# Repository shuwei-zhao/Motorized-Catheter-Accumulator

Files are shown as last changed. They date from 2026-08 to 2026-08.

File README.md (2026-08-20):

# Motorized Catheter Accumulation System

A research prototype for managing the free length of a long, flexible catheter with a translating large-pulley accumulator driven by a lead-screw stepper stage.

> [!IMPORTANT]
> This repository documents only the catheter accumulation and recovery mechanism. The magnetic steering robot, catheter propulsion module, and demonstration specimen shown in the system overview are integration context and are not implemented in this repository.

## 1. Overview

Long magnetic catheters require controlled length management during experiments. Unmanaged excess length can bend unpredictably, become entangled, reduce experimental repeatability, and make manual handling difficult.

This prototype addresses that problem with a motorized translating-pulley accumulator. A large guiding pulley is mounted on a linear carriage and moves along an MGN12 rail. The catheter is routed around the pulley, so translating the carriage changes the available routing length without winding the catheter onto a rotating spool. A T8 lead screw and stepper motor provide linear actuation, while an Arduino UNO and a Python desktop application provide motion control.

The intended use is laboratory research involving long flexible catheters, including experiments in which the accumulator operates alongside a separate propulsion mechanism and robotic magnetic steering system.

## 2. System Architecture

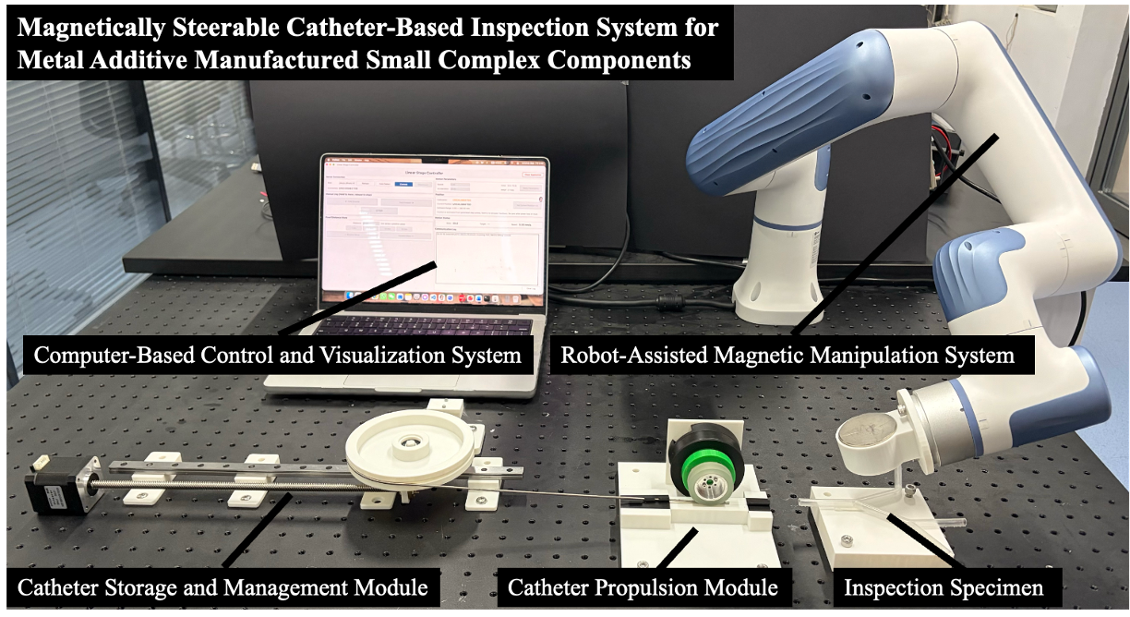
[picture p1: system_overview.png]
Integrated experimental system showing the catheter accumulator in context


The overview image shows the complete experimental setup. The accumulator is the linear module at the lower left; the other labeled modules are outside this repository's scope.

The accumulator consists of three functional layers:

- **Catheter accumulation mechanism:** a large pulley with a catheter groove redirects the catheter and changes the managed path length as it translates.
- **Linear motion stage:** an MGN12 rail, MGN12H carriage, carriage adapter, T8 lead screw, and motor convert rotary motion into controlled horizontal translation.
- **Motor control system:** a Python host application communicates with an Arduino UNO over USB serial. The Arduino generates `STEP` and `DIR` signals for a TB6600 stepper driver.

## 3. Mechanical Design Principle

The mechanism is a translating pulley accumulator, not a reel or driven spool. The pulley rotates passively to guide the catheter, while the entire pulley assembly translates along the linear axis.

```text
Stepper motor rotation
        |
        v
Lead screw rotation
        |
        v
Lead-screw nut translation
        |
        v
Linear carriage movement
        |
        v
Large pulley translation
        |
        v
Change in catheter routing length
        |
        v
Catheter accumulation or release
```

When the moving pulley is supported by two approximately parallel catheter segments, translating it changes both segments by nearly the same amount. The first-order geometric relationship is therefore:

**ΔL ≈ 2Δx**

where:

- `ΔL` is the change in managed catheter length.
- `Δx` is the pulley translation distance.

This approximation assumes that the fixed routing points remain stationary and that changes in wrap geometry, catheter stretch, slip, and elastic deformation are small. The sign of `ΔL` depends on the selected positive carriage direction and routing convention.

## 4. Hardware Components

### Mechanical components

| Component | Specification or role |
| --- | --- |
| Linear rail | MGN12, 400 mm guide rail |
| Linear carriage | MGN12H carriage block |
| Carriage adapter | 3D-printed interface between the carriage, pulley assembly, and lead-screw nut |
| Guide pulley | Large pulley with a U-shaped catheter groove |
| Pulley bearings | 608 bearings supporting passive pulley rotation |
| Pulley shaft | Vertical shaft through the bearing-supported pulley |
| Pulley support | 3D-printed support structure for the shaft and bearings |
| Lead screw | T8 lead screw with an 8 mm lead |
| Nominal actuator travel | 300 mm mechanical travel; the supplied control software limits commanded position to 0-280 mm |

### Electrical components

| Component | Role |
| --- | --- |
| Arduino UNO R3 | Serial command handling and real-time step-pulse generation |
| TB6600 stepper driver | Motor phase-current control from `STEP` and `DIR` inputs |
| Lead-screw stepper motor | Drives the T8 lead screw |
| 24 V, 1.5 A laboratory supply | Powers the motor driver and stepper stage |
| Computer | Runs the Python control interface and supplies the USB serial connection |

The firmware is configured for a 200-full-step motor, 8 microsteps, and an 8 mm lead screw, which gives 200 command pulses per millimetre. Confirm the motor, driver switch settings, lead-screw lead, and available supply current before operation.

## 5. Electronics Connection

### Control chain

```text
Computer
   |
Python interface
   |
USB serial at 115200 baud
   |
Arduino UNO R3
   |
STEP / DIR
   |
TB6600 driver
   |
Stepper motor
   |
T8 lead screw and translating pulley carriage
```

### Arduino-to-driver signals

The supplied firmware uses the following common-anode input wiring:

| Arduino UNO | TB6600 input |
| --- | --- |
| `5V` | `PUL+` and `DIR+` |
| Digital pin `D2` | `PUL-` |
| Digital pin `D3` | `DIR-` |
| Not connected | `ENA+` and `ENA-` |

The 24 V supply connects to the TB6600 power input, and the stepper motor connects to the driver's motor outputs according to the driver and motor documentation. Disconnect power before changing wiring. Do not power the motor from the Arduino.

If the application's **Forward** command produces the wrong physical direction, change `FORWARD_DIR_LEVEL` in the Arduino firmware from `HIGH` to `LOW`, then compile and upload it again.

## 6. Software Usage

### Arduino firmware

The Arduino sketch is located at:

```text
Software/Arduino/Catheter_Accumulator_Controller/Catheter_Accumulator_Controller.ino
```

To upload it:

1. Disconnect motor power and verify the signal wiring.
2. Open the sketch in the Arduino IDE.
3. Select **Arduino UNO** and the correct USB serial port.
4. Compile and upload the sketch.
5. Reconnect motor power only after checking the driver current and microstep settings.

No third-party Arduino library is required. The sketch uses Arduino core headers and standard C/C++ headers.

### Python controller

The host application is located at:

```text
Software/Python/Catheter_Accumulator_Controller.py
```

Python 3 with Tkinter is required. Create an isolated environment and install the serial dependency:

```bash
cd Software/Python
python3 -m venv .venv
source .venv/bin/activate
python -m pip install -r requirements.txt
python Catheter_Accumulator_Controller.py
```

On Windows, activate the environment with `.venv\Scripts\activate` before running the final two commands. If Tkinter is not included with the Python installation, install the platform's Tk package separately.

### Initial operation

1. Power the control electronics and start the Python application.
2. Refresh the serial-port list, select the Arduino, and connect.
3. At low speed, hold the jog control to move the carriage to the chosen mechanical zero position.
4. Select **Set Current Position = 0**.
5. Enter the desired speed, acceleration, and move distance, then command forward or reverse motion.
6. Use **STOP** immediately if the mechanism approaches an obstruction or travel boundary.

The application supports manual jogging, fixed-distance moves, speed and acceleration settings, status reporting, and stop commands. Communication uses newline-terminated ASCII messages at 115200 baud.

> [!WARNING]
> The prototype has no encoder, home sensor, physical limit switch, tension sensor, or emergency-stop circuit. Position is estimated from generated step pulses. The Arduino returns to `UNCALIBRATED` after every reset or power cycle, so the carriage must be re-zeroed manually. The 0-280 mm software limits do not replace physical travel protection.

The firmware communication watchdog stops motion if valid host contact is absent for more than one second. Begin commissioning with low speed and short moves, keep a power disconnect accessible, and prevent the catheter, wiring, and operator from entering pinch points.

## 7. CAD Files

Native CAD sources are stored in [`Hardware/CAD`](Hardware/CAD). They include the large guide pulley, MGN12H carriage adapter, rail base platform, fixed catheter clamp, and compliant-pad mold components.

The current archive contains Autodesk Fusion `.f3d` files and one SOLIDWORKS `.SLDPRT` file. It does not yet include validated STL exports, STEP exchange files, manufacturing drawings, tolerances, or print settings. See the [CAD inventory](Hardware/CAD/README.md) for file-level descriptions.

## 8. Repository Structure

```text
Motorized-Catheter-Accumulator/
├── README.md
├── system_overview.png
├── Software/
│   ├── Arduino/
│   │   └── Catheter_Accumulator_Controller/
│   │       └── Catheter_Accumulator_Controller.ino
│   └── Python/
│       ├── Catheter_Accumulator_Controller.py
│       └── requirements.txt
├── Hardware/
│   └── CAD/
│       ├── README.md
│       ├── Ecoflex_Pad_Mold_Bottom.f3d
│       ├── Ecoflex_Pad_Mold_Top.f3d
│       ├── Fixed_Catheter_Clamp.f3d
│       ├── Guide_Pulley_120mm.f3d
│       ├── Linear_Rail_Base_Platform.SLDPRT
│       └── MGN12H_Carriage_Adapter.f3d
└── .gitignore
```

## 9. Future Development

Possible research extensions include:

- Closed-loop carriage position control with an encoder or linear scale.
- A repeatable homing procedure using limit or home sensors.
- Direct measurement of catheter tension and automatic tension regulation.
- Physical end-of-travel protection and a dedicated emergency-stop circuit.
- Calibration of the relationship between carriage displacement and managed catheter length.
- Coordinated control with a separate catheter propulsion module.
- Integration with a robotic magnetic steering system for complete experimental workflows.

## Research Status

This repository describes an academic research prototype. It is not a medical device, a clinical system, or a commercial product. Verify all mechanical, electrical, and software behavior independently before experimental use.

No open-source license has been granted. Because this is a private research repository, redistribution and reuse require permission from the project owner.

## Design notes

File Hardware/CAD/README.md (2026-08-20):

# CAD Files

This directory contains native CAD source files for the motorized catheter accumulator research prototype. The models should be reviewed against the as-built hardware before manufacturing replacements.

| File | Format | Intended role |
| --- | --- | --- |
| `MGN12H_Carriage_Adapter.f3d` | Autodesk Fusion archive | Connects the pulley assembly and lead-screw nut to the MGN12H carriage |
| `Guide_Pulley_120mm.f3d` | Autodesk Fusion archive | Large catheter-routing pulley |
| `Linear_Rail_Base_Platform.SLDPRT` | SOLIDWORKS part | Base platform beneath the linear rail |
| `Fixed_Catheter_Clamp.f3d` | Autodesk Fusion archive | Fixed catheter clamp component |
| `Ecoflex_Pad_Mold_Top.f3d` | Autodesk Fusion archive | Upper part of the compliant pad mold or fixture |
| `Ecoflex_Pad_Mold_Bottom.f3d` | Autodesk Fusion archive | Lower part of the compliant pad mold |

The repository currently contains the available native CAD sources only. Mesh exports, neutral STEP files, manufacturing drawings, and verified print settings are not yet included.

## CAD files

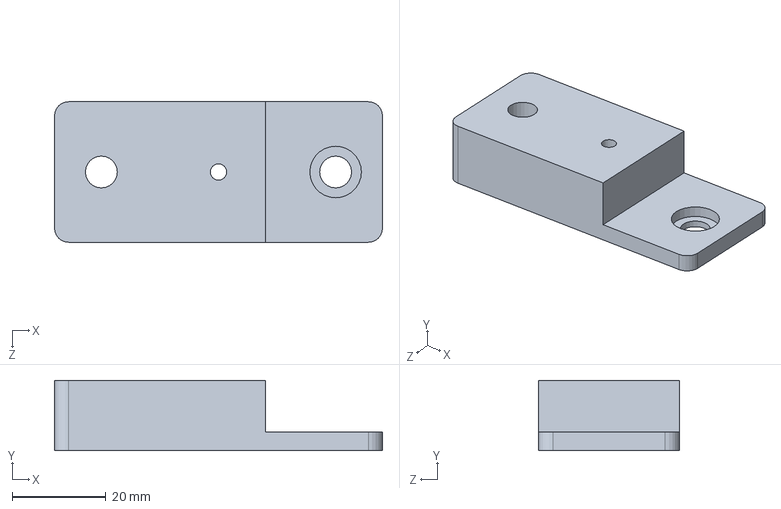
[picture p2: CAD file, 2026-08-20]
Hardware/CAD/Linear_Rail_Base_Platform.SLDPRT
70.0 x 15.0 x 30.0 mm

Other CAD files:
Hardware/CAD/Ecoflex_Pad_Mold_Bottom.f3d
Hardware/CAD/Ecoflex_Pad_Mold_Top.f3d
Hardware/CAD/Fixed_Catheter_Clamp.f3d
Hardware/CAD/Guide_Pulley_120mm.f3d
Hardware/CAD/MGN12H_Carriage_Adapter.f3d

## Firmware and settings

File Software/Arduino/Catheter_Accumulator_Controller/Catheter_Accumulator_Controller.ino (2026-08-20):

// ============================================================================
// Motorized catheter accumulator firmware for Arduino UNO R3, TB6600, and T8 stage
//
// Verified common-anode wiring:
//   Arduino 5V -> PUL+ / DIR+
//   Arduino D2 -> PUL-
//   Arduino D3 -> DIR-
//   ENA not connected
//
// The optocoupler conducts while PUL- is LOW, so the idle PUL level must be HIGH.
// Motor: 200 full steps/rev * 8 microsteps / 8 mm lead = 200 pulses/mm.
//
// Direction check:
// If Forward in the GUI moves the stage in the wrong physical direction, change
// FORWARD_DIR_LEVEL below from HIGH to LOW and upload the firmware again.
//
// This system has no encoder, home sensor, or physical limit switch. Position is
// estimated only from step pulses that were actually generated. Every power cycle
// or reset starts in UNCALIBRATED; the firmware never assumes the real position is 0.
// ============================================================================

#include <Arduino.h>
#include <math.h>
#include <stdlib.h>
#include <string.h>

const uint8_t PUL_PIN = 2;
const uint8_t DIR_PIN = 3;

// Change only HIGH to LOW if the physical direction is reversed.
const uint8_t FORWARD_DIR_LEVEL = HIGH;
const uint8_t REVERSE_DIR_LEVEL = (FORWARD_DIR_LEVEL == HIGH) ? LOW : HIGH;

const int MOTOR_STEPS_PER_REV = 200;
const int MICROSTEPS = 8;
const float LEAD_MM_PER_REV = 8.0f;
const float PULSES_PER_MM =
    ((float)MOTOR_STEPS_PER_REV * (float)MICROSTEPS) / LEAD_MM_PER_REV;

const float MIN_POSITION_MM = 0.0f;
const float MAX_POSITION_MM = 280.0f;
const float SOFTWARE_TRAVEL_MM = MAX_POSITION_MM - MIN_POSITION_MM;
const long MIN_POSITION_PULSES = 0L;
const long MAX_POSITION_PULSES = 56000L;  // 280 mm * 200 pulse/mm

const float MIN_SPEED_MM_S = 0.5f;
const float MAX_SPEED_MM_S = 15.0f;
const float DEFAULT_SPEED_MM_S = 5.0f;

const float MIN_ACCEL_MM_S2 = 1.0f;
const float MAX_ACCEL_MM_S2 = 100.0f;
const float DEFAULT_ACCEL_MM_S2 = 20.0f;

const unsigned long DIR_SETUP_US = 100UL;
const unsigned long WATCHDOG_TIMEOUT_MS = 1000UL;
const unsigned long STATUS_INTERVAL_MS = 200UL;
const uint8_t SERIAL_BUFFER_SIZE = 80;

enum MotionState {
  IDLE,
  JOG_FORWARD,
  JOG_REVERSE,
  MOVE_TO_TARGET
};

MotionState motionState = IDLE;
bool calibrated = false;
long currentPositionPulses = 0L;
long targetPositionPulses = 0L;
int8_t motionDirection = 0;  // +1 Forward, -1 Reverse

float commandedSpeedMmS = DEFAULT_SPEED_MM_S;
float commandedAccelMmS2 = DEFAULT_ACCEL_MM_S2;
float currentSpeedPps = 0.0f;

bool pulseIsLow = false;
bool finishMoveAfterPulse = false;
unsigned long nextEdgeUs = 0UL;
unsigned long currentHalfPeriodUs = 500UL;

unsigned long lastHostContactMs = 0UL;
unsigned long lastStatusMs = 0UL;

char serialBuffer[SERIAL_BUFFER_SIZE];
uint8_t serialLength = 0;

const __FlashStringHelper *stateName(MotionState state) {
  switch (state) {
    case JOG_FORWARD: return F("JOG_FWD");
    case JOG_REVERSE: return F("JOG_REV");
    case MOVE_TO_TARGET: return F("MOVE");
    default: return F("IDLE");
  }
}

bool timeReached(unsigned long now, unsigned long deadline) {
  return (long)(now - deadline) >= 0;
}

void printPositionLine() {
  Serial.print(F("POS "));
  if (!calibrated) {
    Serial.println(F("UNCALIBRATED"));
  } else {
    Serial.println(currentPositionPulses / PULSES_PER_MM, 3);
  }
}

void printStateLine() {
  Serial.print(F("STATE "));
  Serial.println(stateName(motionState));
}

void printTargetLine() {
  Serial.print(F("TARGET "));
  if (motionState == MOVE_TO_TARGET) {
    Serial.println(targetPositionPulses / PULSES_PER_MM, 3);
  } else {
    Serial.println(F("--"));
  }
}

void sendStatus() {
  // A status line fits in the UNO TX buffer and is sent every 200 ms during motion.
  Serial.print(F("STATUS "));
  Serial.print(stateName(motionState));
  Serial.print(' ');
  if (calibrated) {
    Serial.print(currentPositionPulses / PULSES_PER_MM, 3);
  } else {
    Serial.print(F("UNCALIBRATED"));
  }
  Serial.print(' ');
  if (motionState == MOVE_TO_TARGET) {
    Serial.println(targetPositionPulses / PULSES_PER_MM, 3);
  } else {
    Serial.println('-');
  }
}

void forcePulseIdle() {
  digitalWrite(PUL_PIN, HIGH);
  pulseIsLow = false;
  finishMoveAfterPulse = false;
}

void stopMotion(bool reportStopped) {
  bool wasMoving = (motionState != IDLE);
  forcePulseIdle();
  motionState = IDLE;
  motionDirection = 0;
  currentSpeedPps = 0.0f;

  if (reportStopped || wasMoving) {
    Serial.println(F("STOPPED"));
  }
  printStateLine();
  printPositionLine();
  printTargetLine();
}

unsigned long halfPeriodForSpeed(float speedPps) {
  if (speedPps < 1.0f) speedPps = 1.0f;
  float halfPeriod = 500000.0f / speedPps;
  if (halfPeriod < 150.0f) halfPeriod = 150.0f;
  if (halfPeriod > 500000.0f) halfPeriod = 500000.0f;
  return (unsigned long)(halfPeriod + 0.5f);
}

float firstPulseSpeedPps() {
  // Speed after the first pulse from rest, derived from v^2 = 2*a*s.
  float accelPps2 = commandedAccelMmS2 * PULSES_PER_MM;
  float speed = sqrtf(2.0f * accelPps2);
  float maximum = commandedSpeedMmS * PULSES_PER_MM;
  return (speed < maximum) ? speed : maximum;
}

void setDirection(int8_t direction) {
  digitalWrite(DIR_PIN, direction > 0 ? FORWARD_DIR_LEVEL : REVERSE_DIR_LEVEL);
}

void beginMotion(MotionState newState, int8_t direction) {
  motionState = newState;
  motionDirection = direction;
  currentSpeedPps = firstPulseSpeedPps();
  currentHalfPeriodUs = halfPeriodForSpeed(currentSpeedPps);
  pulseIsLow = false;
  finishMoveAfterPulse = false;
  setDirection(direction);
  nextEdgeUs = micros() + DIR_SETUP_US;
}

bool nextPulseWouldCrossLimit() {
  if (!calibrated) return false;
  long nextPosition = currentPositionPulses + motionDirection;
  return nextPosition < MIN_POSITION_PULSES ||
         nextPosition > MAX_POSITION_PULSES;
}

void stopAtLimit() {
  bool atMaximum = (motionDirection > 0);
  forcePulseIdle();
  motionState = IDLE;
  motionDirection = 0;
  currentSpeedPps = 0.0f;
  printStateLine();
  printPositionLine();
  printTargetLine();
  Serial.print(F("LIMIT "));
  Serial.println(atMaximum ? F("MAX") : F("MIN"));
}

void finishFixedMove() {
  forcePulseIdle();
  motionState = IDLE;
  motionDirection = 0;
  currentSpeedPps = 0.0f;
  Serial.println(F("DONE"));
  printStateLine();
  printPositionLine();
  printTargetLine();
}

void updateSpeedAfterPulse() {
  float accelPps2 = commandedAccelMmS2 * PULSES_PER_MM;
  float maximumPps = commandedSpeedMmS * PULSES_PER_MM;
  float accelerated = sqrtf(currentSpeedPps * currentSpeedPps + 2.0f * accelPps2);
  if (accelerated > maximumPps) accelerated = maximumPps;

  if (motionState == MOVE_TO_TARGET) {
    long remaining = labs(targetPositionPulses - currentPositionPulses);
    // Ensure the stage can decelerate to zero within the remaining pulses.
    // Short moves naturally produce a triangular velocity profile.
    float stoppingLimited = sqrtf(2.0f * accelPps2 * (float)remaining);
    currentSpeedPps = (accelerated < stoppingLimited) ? accelerated : stoppingLimited;
  } else {
    // Jog accelerates only at startup and stops immediately on release or STOP.
    currentSpeedPps = accelerated;
  }

  if (currentSpeedPps < 1.0f) currentSpeedPps = 1.0f;
  currentHalfPeriodUs = halfPeriodForSpeed(currentSpeedPps);
}

void updatePulseGenerator() {
  if (motionState == IDLE) return;

  unsigned long now = micros();
  if (!timeReached(now, nextEdgeUs)) return;

  if (!pulseIsLow) {
    if (nextPulseWouldCrossLimit()) {
      stopAtLimit();
      return;
    }

    // Common anode: LOW begins the active pulse. Update position only when a
    // pulse is actually generated.
    digitalWrite(PUL_PIN, LOW);
    pulseIsLow = true;
    currentPositionPulses += motionDirection;
    nextEdgeUs = now + currentHalfPeriodUs;

    if (motionState == MOVE_TO_TARGET &&
        currentPositionPulses == targetPositionPulses) {
      finishMoveAfterPulse = true;
    }
  } else {
    digitalWrite(PUL_PIN, HIGH);
    pulseIsLow = false;

    if (finishMoveAfterPulse) {
      finishFixedMove();
      return;
    }

    updateSpeedAfterPulse();
    nextEdgeUs = now + currentHalfPeriodUs;
  }
}

bool parseFiniteFloat(const char *text, float &value) {
  if (text == NULL || *text == '\0') return false;
  char *endPointer;
  double parsed = strtod(text, &endPointer);
  while (*endPointer == ' ' || *endPointer == '\t') endPointer++;
  if (*endPointer != '\0' || isnan(parsed) || isinf(parsed)) return false;
  value = (float)parsed;
  return true;
}

void acknowledgeHostContact() {
  lastHostContactMs = millis();
}

void handleSetSpeed(const char *argument) {
  float value;
  if (!parseFiniteFloat(argument, value) ||
      value < MIN_SPEED_MM_S || value > MAX_SPEED_MM_S) {
    Serial.println(F("ERR INVALID_PARAMETER"));
    return;
  }
  if (motionState != IDLE) {
    Serial.println(F("ERR BUSY"));
    return;
  }
  commandedSpeedMmS = value;
  acknowledgeHostContact();
  Serial.print(F("ACK SPEED "));
  Serial.println(commandedSpeedMmS, 3);
}

void handleSetAccel(const char *argument) {
  float value;
  if (!parseFiniteFloat(argument, value) ||
      value < MIN_ACCEL_MM_S2 || value > MAX_ACCEL_MM_S2) {
    Serial.println(F("ERR INVALID_PARAMETER"));
    return;
  }
  if (motionState != IDLE) {
    Serial.println(F("ERR BUSY"));
    return;
  }
  commandedAccelMmS2 = value;
  acknowledgeHostContact();
  Serial.print(F("ACK ACCEL "));
  Serial.println(commandedAccelMmS2, 3);
}

void handleJog(int8_t direction) {
  if (motionState != IDLE) {
    Serial.println(F("ERR BUSY"));
    return;
  }

  if (calibrated) {
    if (direction > 0 && currentPositionPulses >= MAX_POSITION_PULSES) {
      Serial.println(F("LIMIT MAX"));
      return;
    }
    if (direction < 0 && currentPositionPulses <= MIN_POSITION_PULSES) {
      Serial.println(F("LIMIT MIN"));
      return;
    }
  }

  acknowledgeHostContact();
  beginMotion(direction > 0 ? JOG_FORWARD : JOG_REVERSE, direction);
  Serial.print(F("ACK JOG "));
  Serial.println(direction > 0 ? F("FWD") : F("REV"));
  printStateLine();
  printTargetLine();
}

void handleMove(const char *argument) {
  if (!calibrated) {
    Serial.println(F("ERR NOT_ZEROED"));
    return;
  }
  if (motionState != IDLE) {
    Serial.println(F("ERR BUSY"));
    return;
  }

  float distanceMm;
  if (!parseFiniteFloat(argument, distanceMm) || distanceMm == 0.0f) {
    Serial.println(F("ERR INVALID_PARAMETER"));
    return;
  }

  // A relative move larger than the full software travel is always invalid.
  // Check it first to avoid overflow when converting a large float to long.
  if (fabsf(distanceMm) > SOFTWARE_TRAVEL_MM) {
    Serial.println(F("ERR OUT_OF_RANGE"));
    return;
  }

  long deltaPulses = lroundf(distanceMm * PULSES_PER_MM);
  if (deltaPulses == 0L) {
    Serial.println(F("ERR INVALID_PARAMETER"));
    return;
  }

  long requestedTarget = currentPositionPulses + deltaPulses;
  if (requestedTarget < MIN_POSITION_PULSES ||
      requestedTarget > MAX_POSITION_PULSES) {
    Serial.println(F("ERR OUT_OF_RANGE"));
    return;  // Reject the entire MOVE instead of clipping the distance.
  }

  targetPositionPulses = requestedTarget;
  acknowledgeHostContact();
  beginMotion(MOVE_TO_TARGET, deltaPulses > 0L ? 1 : -1);
  Serial.println(F("ACK MOVE"));
  printTargetLine();
  printStateLine();
}

void handleZero() {
  if (motionState != IDLE) {
    Serial.println(F("ERR BUSY"));
    return;
  }
  currentPositionPulses = 0L;
  targetPositionPulses = 0L;
  calibrated = true;
  acknowledgeHostContact();
  Serial.println(F("ACK ZERO"));
  printPositionLine();
  printStateLine();
  printTargetLine();
}

void handleCommand(char *command) {
  while (*command == ' ' || *command == '\t') command++;
  size_t length = strlen(command);
  while (length > 0 &&
         (command[length - 1] == ' ' || command[length - 1] == '\t')) {
    command[--length] = '\0';
  }

  if (strcmp(command, "HB") == 0) {
    acknowledgeHostContact();
  } else if (strcmp(command, "PING") == 0) {
    acknowledgeHostContact();
    Serial.println(F("PONG"));
  } else if (strcmp(command, "GET STATUS") == 0) {
    acknowledgeHostContact();
    sendStatus();
    Serial.print(F("PARAM SPEED="));
    Serial.print(commandedSpeedMmS, 3);
    Serial.print(F(" ACCEL="));
    Serial.println(commandedAccelMmS2, 3);
  } else if (strcmp(command, "STOP") == 0) {
    acknowledgeHostContact();
    stopMotion(true);
  } else if (strcmp(command, "ZERO") == 0) {
    handleZero();
  } else if (strcmp(command, "JOG FWD") == 0) {
    handleJog(1);
  } else if (strcmp(command, "JOG REV") == 0) {
    handleJog(-1);
  } else if (strncmp(command, "SET SPEED ", 10) == 0) {
    handleSetSpeed(command + 10);
  } else if (strncmp(command, "SET ACCEL ", 10) == 0) {
    handleSetAccel(command + 10);
  } else if (strncmp(command, "MOVE ", 5) == 0) {
    handleMove(command + 5);
  } else {
    Serial.println(F("ERR INVALID_COMMAND"));
  }
}

void readSerialCommands() {
  // Process at most 16 bytes per loop so long serial input cannot monopolize
  // execution and disturb pulse timing.
  uint8_t processed = 0;
  while (Serial.available() > 0 && processed < 16) {
    char incoming = (char)Serial.read();
    processed++;

    if (incoming == '\n') {
      serialBuffer[serialLength] = '\0';
      if (serialLength > 0) handleCommand(serialBuffer);
      serialLength = 0;
    } else if (incoming != '\r') {
      if (serialLength < SERIAL_BUFFER_SIZE - 1) {
        serialBuffer[serialLength++] = incoming;
      } else {
        serialLength = 0;
        Serial.println(F("ERR LINE_TOO_LONG"));
      }
    }
  }
}

void checkCommunicationWatchdog() {
  if (motionState == IDLE) return;
  if ((unsigned long)(millis() - lastHostContactMs) > WATCHDOG_TIMEOUT_MS) {
    stopMotion(false);
    Serial.println(F("ERR LINK_TIMEOUT"));
  }
}

void sendPeriodicStatus() {
  unsigned long now = millis();
  if ((unsigned long)(now - lastStatusMs) >= STATUS_INTERVAL_MS) {
    lastStatusMs = now;
    sendStatus();
  }
}

void setup() {
  pinMode(PUL_PIN, OUTPUT);
  pinMode(DIR_PIN, OUTPUT);
  digitalWrite(PUL_PIN, HIGH);  // Common-anode idle level; no motion at startup.
  digitalWrite(DIR_PIN, FORWARD_DIR_LEVEL);

  Serial.begin(115200);
  lastHostContactMs = millis();
  lastStatusMs = millis();

  Serial.println(F("READY"));
  printPositionLine();
  printStateLine();
  printTargetLine();
}

void loop() {
  // Update the pulse generator twice to reduce edge jitter from serial parsing.
  updatePulseGenerator();
  readSerialCommands();
  updatePulseGenerator();
  checkCommunicationWatchdog();
  sendPeriodicStatus();
}
